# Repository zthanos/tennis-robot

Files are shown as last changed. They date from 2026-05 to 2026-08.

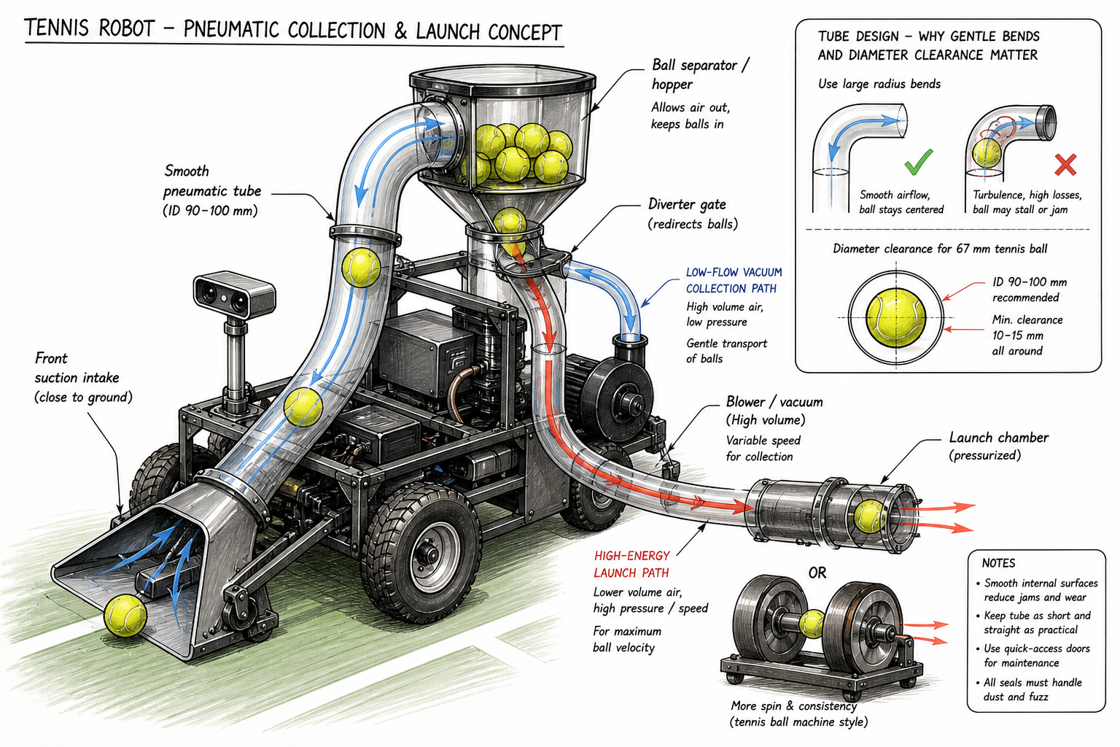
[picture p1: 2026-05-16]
docs/images/pneumatic-collection-launch-concept.png

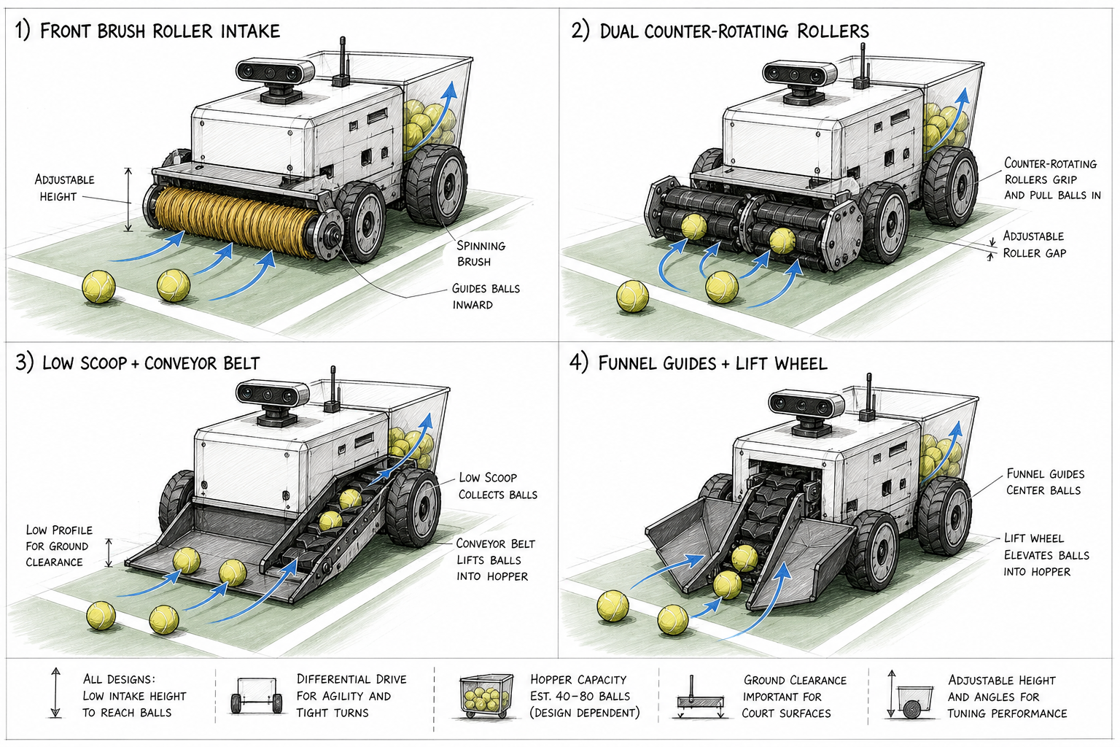
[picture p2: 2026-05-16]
docs/images/collector-concepts.png

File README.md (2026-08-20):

# Tennis Robot Simulation Starter

## Architecture Reset Notice

The current Webots controller and world are now treated as **legacy reference**
for the next implementation phase. New work should follow
`docs/process/architecture-implementation-guide-el.md` and the active baseline plans in
`docs/` before extending the existing controller behavior.

This is a first simulation-first experiment for a tennis-ball collecting and serving robot.

The initial goal is intentionally small:

- create a virtual tennis court;
- scatter tennis balls at random positions;
- place a differential-drive robot with a camera on the court;
- detect tennis balls from the camera stream using Python/OpenCV.

The project starts with **Webots + Python** because it is easier to get moving than a full ROS/Gazebo stack. ROS 2 can be added once perception and basic navigation behavior are proven.

## Project Layout

```text
controllers/
  ball_detector/
    ball_detector.py        # Webots Python controller
scripts/
  generate_balls.py         # Generate random Webots ball nodes
worlds/
  tennis_court.wbt          # Webots world
docker-compose.yml          # Optional Python dev container
Dockerfile                  # Optional Python/OpenCV environment
Dockerfile.webots           # Webots GUI container with noVNC
pyproject.toml              # Python deps managed with uv
```

## Quick Start

Install Webots on the host machine, then start local Webots and the remote-control console with:

```powershell
.\scripts\start_local_webots_control.ps1
```

Then press Play in Webots and open:

```text
http://127.0.0.1:8081
```

The script starts Webots with `USE_RGB_VISION=true` and points both Webots and the control panel at the same local `runtime/*.json` files. If Webots is installed somewhere unusual, pass the executable path:

```powershell
.\scripts\start_local_webots_control.ps1 -WebotsPath "C:\Path\to\webots.exe"
```

If Webots was already open, close it before running the script so it picks up the project Python/OpenCV environment. To force that from the script:

```powershell
.\scripts\start_local_webots_control.ps1 -RestartWebots
```

To run the ROS 2/Webots stack through WSLg with GPU acceleration, start it from
a WSL shell instead of Windows PowerShell:

```bash
cd /mnt/c/Users/thano/projects/diy/tennis-robot
bash scripts/start_local_webots_control_wslg.sh --build
```

The WSLg launcher uses the `ros2-wslg` Docker profile and defaults to the
`RX 7900 XTX` Mesa D3D12 adapter. Override it when needed:

```bash
bash scripts/start_local_webots_control_wslg.sh --adapter "AMD Radeon RX 7900 XTX"
```

The optional control panel runs from WSL and uses the project Python deps. If
WSL does not have `uv` yet:

```bash
curl -LsSf https://astral.sh/uv/install.sh | sh
source ~/.bashrc
```

You can still open the world manually:

```text
worlds/tennis_court.wbt
```

The robot controller is:

```text
controllers/ball_detector/ball_detector.py
```

When the simulation runs, the controller reads from the robot camera, detects tennis-ball-colored blobs, and draws detection rectangles on the Webots camera display.
The controller uses the simulated OAK depth stream for ball distance; RGB-only detections without valid depth are not converted into ball positions.
Detections are projected into robot-base and court/world XY coordinates using the front camera mount and the robot pose, so downstream navigation can reason in meters instead of image pixels.

The current world includes **Concept A: Funnel + Wide Intake Roller** as the front collector module:

- a level (un-pitched) 4WD skid-steer chassis with four driven 180 mm wheels, two per side (no casters);
- orange funnel plates and a low intake lip on the robot front;
- a rubber-like wide intake roller driven by `lift_wheel_motor` (historical device name);
- a transparent visual hopper raised for throw-mode gravity feed;
- a simulated intake zone that removes a tennis ball once the collector state machine captures it.
- a top-mounted `front_camera` plus aligned `front_depth` range finder representing the OAK-D-Lite AF RGB-D role for tennis-ball detection, depth, and targeted looks into shadow zones;
- a low-mounted 360-degree `front_lidar` representing the Waveshare/Slamtec RPLIDAR C1 role for real-time court boundaries, obstacles, range, shadow zones, and route costmaps.

## Robot Description Source

The robot description source is URDF xacro:

```text
ros2_ws/src/tennis_robot/urdf/tennis_robot.urdf.xacro
```

Component xacro files live under:

```text
ros2_ws/src/tennis_robot/urdf/components/
```

Edit the URDF xacro source when changing robot dimensions, wheel geometry,
sensor mounts, Gazebo sensor sections, or controller geometry constants.
Generate the runtime URDF locally with:

```powershell
uv run --with xacro python scripts/generate_robot_urdf.py
```

Inside the Gazebo Docker image, `ros-humble-xacro` is installed, so
`python3 scripts/generate_robot_urdf.py` is enough.

The Gazebo launch files regenerate this runtime file on every launch:

```text
runtime/tennis_robot.urdf
```

The tennis court world stays SDF and no longer includes `model://tennis_robot`.
Instead, the launch file spawns the generated URDF into Gazebo. To check whether
the generated URDF matches the xacro source:

```powershell
uv run --with xacro python scripts/generate_robot_urdf.py --check
```

The generated URDF is ignored by Git via `runtime/`. Treat it as a runtime/debug
view, not as a second source file.

The Webots court is modeled after the reference clay court photos:

- red clay playing surface with lighter wear/brush marks;
- off-white tennis lines;
- tall dark perimeter fencing for survey/depth measurements;
- side stone patio with planter boxes, a chair/umbrella area, floodlight poles, and green visual mass outside the court.

The controller behavior is:

```text
idle -> scan -> align -> approach -> capture -> collected
```

The Webots camera display overlays the current collector state and collected-ball count. The controller starts in `idle` and waits for a command from the Python control panel before it begins collecting. Ball distance is currently estimated from the top camera image, while the low 360-degree `front_lidar` provides range data for survey/navigation telemetry and the intended simulated contract for live obstacle mapping.

## Remote Control Console

Run the web remote-control console:

```powershell
uv run python scripts/control_panel.py
```

Then open:

```text
http://127.0.0.1:8081
```

Στο Raspberry Pi το κύριο ROS launch εκθέτει το operator console στο LAN. Για
αυτόνομο, WPA2/WPA3-protected Wi-Fi στο γήπεδο χωρίς router ή Internet, δες το
[Field Wi-Fi AP provisioning](docs/network/field-wifi-ap.md). Με τις default
ρυθμίσεις το τηλέφωνο ανοίγει `http://10.42.0.1:8081`.

The console has navigation for:

- **Dashboard**: requested mode, actual controller state, ball detection, collected count, and latest command stream.
- **Control**: send `idle`, `collect`, `collect_pattern`, `search`, and `survey` commands, plus a live court map with detected balls, same-side/across-net status, planned route, and pickup order.
- **Telemetry**: live robot pose, collector output, observation fields, survey target/range, and raw status JSON.
- **Command Stats**: per-mode command counts and last command metadata.
- **History**: recent command audit trail.

Use **Start Collection** to write `mode=collect` to `runtime/robot_command.json`; the Webots controller polls that file and starts the collector state machine. Use **Stop** to return the robot to `idle`. The controller also writes live diagnostics to `runtime/robot_status.json`, while command history is appended to `runtime/robot_command_history.jsonl`. You can override paths for both processes with `ROBOT_COMMAND_FILE`, `ROBOT_STATUS_FILE`, and `ROBOT_COMMAND_HISTORY_FILE` if the UI and Webots are launched from different working directories.
Use **Collect Pattern** to write `mode=collect_pattern`: the controller follows the half-court boundary/lane search pattern, interrupts on a same-side OAK-D target, hands off to the Concept A collector state machine, verifies collection, then resumes from the saved search marker.

To visualize the scan-first collection plan directly in Webots, start the controller with:

```powershell
$env:ROUTE_VISUALIZATION="true"
$env:ROUTE_VISUALIZATION_PRESET="fast"  # or "thorough"
```

When collection starts, the supervisor draws a route line on the court and ball markers for the current plan. `fast` hides risky balls from the plan; `thorough` shows the full reachable route for the robot's current side of the court. The overlay refreshes after simulated collection events and clears when the robot leaves collect mode.

Use **Survey court** to drive a boustrophedon measurement pattern across the court. The controller visits rows across the court, samples the front depth reading at each waypoint, and writes measurements to:

```text
runtime/court_survey.csv
```

The survey CSV includes robot position, heading, front range reading, distance to the four outer fences, and distances to the nearest singles sideline, doubles sideline, baseline, and service line.

The movement speed defaults are deliberately conservative in Docker:

```text
COLLECTOR_SCAN_ANGULAR_SPEED_RAD_S=0.35
COLLECTOR_MAX_ALIGN_ANGULAR_SPEED_RAD_S=0.45
COLLECTOR_ALIGN_ANGULAR_GAIN=1.4
COLLECTOR_APPROACH_SPEED_M_S=0.12
COLLECTOR_CAPTURE_SPEED_M_S=0.05
COLLECTOR_REVERSE_SPEED_M_S=0.08
ROBOT_MAX_WHEEL_SPEED_RAD_S=3.5
```

Increase `COLLECTOR_APPROACH_SPEED_M_S` only after the robot reliably keeps the ball in view during `align` and `approach`.

## Generate New Random Ball Positions

The world contains a marked block where tennis ball nodes are generated. To print a new deterministic set of balls:

With `uv` installed:

```powershell
uv run python scripts/generate_balls.py --count 18 --seed 7
```

Copy the output between the `# BALLS_START` and `# BALLS_END` markers in `worlds/tennis_court.wbt`.
By default the generator uses a realistic tennis-court bias: more balls near the net and the back court, fewer in open mid-court. Use `--distribution uniform` when you need an even random scatter for comparison.

## Optional Docker Dev Shell

Docker is useful for Python tooling and OpenCV experiments, but Webots GUI is usually simpler to run on the host or inside WSLg. The container uses `uv` too.

```powershell
docker compose run --rm sim-dev
uv run python scripts/generate_balls.py --count 18 --seed 7
uv run python -m py_compile controllers/ball_detector/ball_detector.py scripts/generate_balls.py
uv run python scripts/perception_smoke.py
uv run python scripts/collector_behavior_smoke.py
uv run python scripts/survey_behavior_smoke.py
```

## Webots In Docker

The `webots` compose service runs Webots in a virtual X display and exposes it through noVNC.

To start Webots with RGB vision and LiDAR enabled, and launch the remote-control console at the same time:

```powershell
.\scripts\start_webots_control.ps1
```

Then open:

```text
http://localhost:6080/vnc.html
http://127.0.0.1:8081
```

Use `-Build` the first time you want to rebuild the Docker image:

```powershell
.\scripts\start_webots_control.ps1 -Build
```

```powershell
docker compose up webots
```

Then open:

```text
http://localhost:6080/vnc.html
```

The service opens `worlds/tennis_court.wbt` automatically. This is convenient for a reproducible setup, but native Webots on Windows or WSLg may still be smoother for interactive editing.

## OpenSCAD In Docker

### GUI in the browser (no local install)

The `openscad-gui` service runs OpenSCAD on a virtual display and exposes it through noVNC (same idea as the Webots container). Port `6081` avoids clashing with Webots on `6080`.

```powershell
docker compose --profile cad up --build openscad-gui
```

Open:

```text
http://localhost:6081/vnc.html
```

It currently starts without a preloaded model because the old collector and
chassis SCAD files no longer match the active robot. Once a new active model is
added, open it from the mounted `cad/` directory or set `OPENSCAD_FILE`:

```powershell
$env:OPENSCAD_FILE="/workspace/cad/active_robot.scad"
docker compose --profile cad up openscad-gui
```

See `cad/README.md` for the current CAD status and mechanical sources of truth.
Files under `cad/` are the mounted repo workspace, so saves in the GUI write back to your project folder.

### Headless STL export

The `openscad` compose service uses the official `openscad/openscad:bookworm`
image to export future printable CAD files without a GUI:

```powershell
docker compose --profile cad run --rm openscad openscad -o cad/stl/active_robot.stl cad/active_robot.scad
```

## Telemetry

The Webots controller has optional OpenTelemetry instrumentation for simulation data:

- `robot.camera.frames`
- `robot.vision.ball.detections`
- `robot.vision.ball.area`
- `robot.vision.ball.distance`
- `robot.vision.ball.bearing`
- `robot.control.loop.duration`
- `simulation.step` traces

In Docker, telemetry is enabled for the `webots` service and sent to the local OpenTelemetry Collector:

```powershell
docker compose up webots otel-collector
docker compose logs -f otel-collector
```

To watch the robot controller state directly:

```powershell
docker compose logs -f webots
```

Useful controller log lines look like:

```text
control mode changed to collect
mode=collect collector=align visible=True distance=5.03m bearing=-29.5deg balls=0 ball_world=(-3.64,-2.49)
```

For local debugging without a collector, run with:

```powershell
$env:OTEL_ENABLED="true"
$env:OTEL_EXPORTER="console"
```

## Browser Route Simulator

Run the lightweight route simulation panel:

```powershell
uv run python scripts/simulation_panel.py
```

Then open:

```text
http://127.0.0.1:8082
```

This panel is a fast planning sandbox before deeper Webots work. It models the tennis court bounds, half-court or full-court movement area, random 40-50 ball dispersion, fixed obstacles, moving people with safety zones, travel speed, pickup time, scan time, periodic re-scans, and obstacle-aware route planning. During movement it performs continuous lookahead collision checks, pauses for emergency clearance, and replans if a dynamic obstacle enters the active path. It records telemetry for the run, including detected/collectable/blocked balls, total distance, total time, planned and runtime replans, safety stops, near misses, per-leg travel time, and scan/pickup/re-scan events.

## Route Benchmark

Run a Monte Carlo benchmark for the half-court scan/route strategy:

```powershell
uv run python scripts/route_benchmark.py --runs 100 --balls 40
```

The benchmark generates deterministic random scenarios with realistic ball bias, plans two-phase collection, estimates travel time from configured robot speed, and reports average collection rate, total time, distance, expected misses, blocked balls, net/wall risks, obstacle risks, scan events, and replans.

Enable the RPLIDAR C1-style costmap penalty when comparing the camera-only planner against OAK-D ball detection plus a live LiDAR obstacle map:

```powershell
uv run python scripts/route_benchmark.py --runs 100 --balls 40 --lidar-costmap --json-out runtime/route-benchmark-lidar-costmap.json --csv-out runtime/route-benchmark-lidar-costmap.csv
```

Write detailed outputs when comparing planner settings:

```powershell
uv run python scripts/route_benchmark.py --runs 100 --balls 40 --json-out runtime/route-benchmark.json --csv-out runtime/route-benchmark.csv
```

Generate learning-to-rank training data for a future next-ball policy model:

```powershell
uv run python scripts/route_benchmark.py --runs 1000 --balls 40 --training-out runtime/route-training.csv
```

Each training row represents one candidate ball at one planning decision. `selected=1` marks the ball chosen by the planner; `selected=0` marks alternatives. Features include robot pose, ball pose, estimated route distance, travel time, pickup-pose offset, risk type, miss probability, and distances to net, walls, and obstacles.

Train a baseline next-ball policy model from that CSV:

```powershell
uv run python scripts/train_next_ball_policy.py --training-csv runtime/route-training.csv --model-out runtime/next-ball-policy-model.json --metrics-out runtime/next-ball-policy-metrics.json
```

Evaluate the trained model against the planner on fresh scenarios:

```powershell
uv run python scripts/evaluate_next_ball_policy.py --runs 100 --balls 40 --seed 10000 --json-out runtime/next-ball-policy-eval.json --csv-out runtime/next-ball-policy-eval.csv
```

Generate outcome-labeled data when testing alternatives to planner imitation:

```powershell
uv run python scripts/generate_outcome_training.py --runs 300 --balls 40 --rollout-depth 0 --miss-penalty 12 --training-out runtime/route-outcome-training.csv
```

Evaluate a defer/edge-pass policy that leaves risky balls for a second pass:

```powershell
uv run python scripts/evaluate_defer_policy.py --runs 100 --balls 40 --seed 10000 --json-out runtime/defer-policy-eval.json --csv-out runtime/defer-policy-eval.csv
```

Add `--lidar-costmap` to evaluate the same defer/edge-pass policy using LiDAR-aware clearance costs.

The route strategy evaluator also has named presets:

- `thorough`: collect every reachable ball with the baseline LiDAR-aware route planner.
- `balanced`: defer obstacle-risk balls to a second pass, keeping collection coverage high at the cost of more time.
- `fast`: skip risky edge/obstacle balls for early physical tests where speed and low miss risk matter more than full collection.

```powershell
uv run python scripts/evaluate_defer_policy.py --runs 100 --balls 40 --lidar-costmap --strategy-preset fast --json-out runtime/strategy-fast-lidar-eval.json --csv-out runtime/strategy-fast-lidar-eval.csv
uv run python scripts/evaluate_defer_policy.py --runs 100 --balls 40 --lidar-costmap --strategy-preset balanced --json-out runtime/strategy-balanced-lidar-eval.json --csv-out runtime/strategy-balanced-lidar-eval.csv
uv run python scripts/evaluate_defer_policy.py --runs 100 --balls 40 --lidar-costmap --strategy-preset thorough --json-out runtime/strategy-thorough-lidar-eval.json --csv-out runtime/strategy-thorough-lidar-eval.csv
```

Evaluate the scan-first architecture: scan the court, build a batch plan, execute up to `--replan-every` pickups, and replan from the current position when a periodic or blocked-path trigger fires.

```powershell
uv run python scripts/evaluate_scan_replan_strategy.py --runs 100 --balls 40 --lidar-costmap --strategy-preset thorough --json-out runtime/scan-replan-thorough-lidar-eval.json --csv-out runtime/scan-replan-thorough-lidar-eval.csv
uv run python scripts/evaluate_scan_replan_strategy.py --runs 100 --balls 40 --lidar-costmap --strategy-preset fast --json-out runtime/scan-replan-fast-lidar-eval.json --csv-out runtime/scan-replan-fast-lidar-eval.csv
```

For a faster mode without using a preset, deliberately skip risky balls:

```powershell
uv run python scripts/evaluate_defer_policy.py --runs 100 --balls 40 --seed 10000 --skip-risky --json-out runtime/defer-policy-skip-risky-eval.json --csv-out runtime/defer-policy-skip-risky-eval.csv
```

## Next Milestones

Done:

1. Add depth estimation from camera geometry or a simulated depth camera.
2. Convert image detections into robot-base and court/world coordinates.
3. Add a simple behavior loop: rotate, detect nearest ball, drive toward it.
4. Test a simulated collector mechanism.

Next:

1. Add ROS 2 nodes and topics around camera frames, detections, and velocity commands.
2. Publish the world-coordinate detections to a route planner instead of only using the nearest visible ball.
3. Add jam/blocked-intake sensing to the collector state machine.

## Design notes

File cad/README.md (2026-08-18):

# Active CAD status

Active model: **`basket-bin-v2/`** — the sim-validated basket bin v2.1 +
entry hood (debug log #45-#56), parametric OpenSCAD with all dimensions in
`basket-bin-v2/params.scad`. Renders/exports run through the
`docker compose --profile cad` services.

Not yet modelled as manufacturing CAD: chassis frame, two-motor dual-wheel
intake and funnel — see below. Their current layout is documented in
`docs/hardware/chassis-layout-4wd-dual-intake-el.md`.

The previous `3d-printable-base` and `cyber-shell` models described superseded
single-roller, scoop, launcher, 760 x 430 mm chassis, and cosmetic-shell
concepts. They were removed from the working tree on the
`feat/dual-wheel-intake-concept` branch; Git history remains the archive.

`archive/single-motor-geared-intake/` is also historical: it visualizes the
rejected one-motor gear-train option. The active intake has two independent
motors, one per side-pinch wheel.

Current mechanical sources of truth:

- `ros2_ws/src/tennis_robot/urdf/tennis_robot.urdf.xacro`
- `ros2_ws/src/tennis_robot/urdf/components/basket.urdf.xacro`
- `docs/mechanism/dual-wheel-intake-design-el.md`
- `docs/mechanism/basket-bin-redesign-spec-el.md`
- `docs/mechanism/intake-debug-log-el.md`
- `docs/hardware/chassis-layout-4wd-dual-intake-el.md`

The next SCAD model should be generated from the validated 920 x 580 mm 4WD
chassis, dual-wheel intake, and basket v2.1 dimensions. Do not restore an old
model as the default without reconciling it against those sources.

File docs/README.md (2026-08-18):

# Tennis Robot Documentation

Active source-of-truth documents, grouped by topic. When a decision changes,
update the relevant baseline document first, then adjust CAD/software/tests.

## Structure

```text
docs/
  collection-route/   continuous collect_route: spec, design, plan, debug log, Nav2 controller
  perception/         OAK-D perception + measurement-covariance calibration
    covariance/       Gazebo covariance calibration reports (c2 / c2-v2 / c2-v3)
  survey/             court knowledge model + LiDAR court survey (v2) + SLAM
  mechanism/          active dual-wheel intake / funnel / basket + intake debug log
  hardware/           active 4WD layout, BOM, wiring, purchase lists, sensor contract
  process/            architecture guide, delivery contract, validation, board, telemetry
  images/             diagrams referenced by the build plans
  archive/  research/  superseded notes and broad exploratory research (background only)
```

## collection-route/
- `collection-route-rules-el.md` - active specification for the continuous collection route.
- `collection-route-design-el.md` - technical design.
- `collection-route-implementation-plan-el.md` - phased implementation plan.
- `collection-route-optimization-plan-el.md` - constraint register and measured plan for the shortest safe full route.
- `collection-route-phase7-acceptance-plan-el.md` - Gazebo acceptance scenarios (S1-S8).
- `collection-route-debug-log-el.md` - **running debug log** (every collect_route change lands here).
- `collection-nav2-controller-{rules,design,implementation-plan}-el.md` - C++ CollectionFollowPath controller.
- `collector-controller-cheat-sheet.md`, `collector-wiring-reference-el.md` - collector bring-up.
- `mission-dashboard-plan-el.md` - mission-control dashboard evolution plan.

## perception/
- `perception-oakd-sim-el.md` - simulated OAK-D pipeline / `BallDetectionArray` contract.
- `oak-d-adapter-contract.md` - OAK-D adapter contract.
- `perception-measurement-covariance-calibration-{rules,design,implementation-plan}-el.md`.
- `covariance/` - Gazebo perception-covariance calibration reports and scenario.

## survey/
- `court-knowledge-model-specification.md` - environment knowledge model + definition of done.
- `court-survey-v2-spec-el.md` - **active, as-built** LiDAR court survey spec.
- `slam-mapping-el.md` - SLAM mapping notes.

## mechanism/
- `intake-debug-log-el.md` - **running debug log** for the intake/collector mechanism.
- `dual-wheel-intake-design-el.md`, `intake-concept-decision-el.md`, `intake-bench-sweep-report-el.md`.
- `basket-bin-redesign-spec-el.md`.

## hardware/
- Purchase/build: `chassis-layout-4wd-dual-intake-el.md`, `prototype-purchase-list-el.md`, `hardware-bom-el.md`, `ordered-parts.md`.
- Wiring/setup: `motion-perfboard-wiring-el.md`, `ros2-control-migration-el.md`, `ubuntu-dual-boot-handoff.md`.
- Contracts: `sensor-topic-contract-el.md`, `hardware-glossary.md`.
- `../arduino/collector/` - Arduino bring-up sketches (collector motor, encoder, IR beam).

## process/
- `architecture-implementation-guide-el.md` - source-of-truth implementation guide.
- `feature-delivery-contract-el.md` - spec/design/plan workflow for substantial features.
- `pi-deployment-plan-el.md` - Raspberry Pi deployment + Humble→Jazzy migration plan.
- `validation-plan-el.md`, `project-board-plan-el.md`, `telemetry-architecture-el.md`.

## Archive

`docs/archive/` and `docs/research/` hold superseded plans and broad exploratory
research. Treat them as background only.

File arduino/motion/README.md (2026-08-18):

# Motion MCU (Arduino Mega) — drive firmware

`motion_mega/motion_mega.ino` — real-time / safety layer for the 4WD skid-steer
drive. Two BTS7960 drivers (one per side), four encoders. The host (PC now, Pi
later) sends high-level per-side duty over USB serial; the Mega handles arming,
ramp, timeout and E-stop. USB serial is host-agnostic, so what you validate on
the PC transfers unchanged to the Pi.

## Bench test (motors → PC)

1. **Power:** drive motors need a strong 12V supply (or the battery) — **NOT**
   the 12V/2A collector PSU (4 motors stall ~28A). USB only powers Arduino logic.
2. **Common ground:** Arduino GND + both BTS7960 GND + 12V PSU GND tied together.
3. **Wheels OFF the ground** for first runs.
4. Flash `motion_mega.ino` to the Mega.
5. Run the host test:
   ```bash
   uv run python scripts/test_motion_serial.py --port /dev/ttyACM0   # or COM5 on Windows
   ```
6. `arm` → `f 0.2` (forward, low duty) → watch encoder counts move. `stop`,
   then test `b`, `l`, `r`. Confirm each side's direction + encoder sign.
   Do **one side at a time** first: `m 0.2 0` then `m 0 0.2`.

## Serial protocol (115200, `\n`-terminated)

| Host → Mega | Meaning |
|---|---|
| `ARM` | enable drivers (only if E-stop ok) |
| `DISARM` | disable + stop |
| `M <left> <right>` | per-side duty, floats `[-1.0, 1.0]` (also a heartbeat) |
| `STOP` | target duty 0, stays armed (also a heartbeat) |
| `PING` | heartbeat only → replies `PONG` |

| Mega → Host | Meaning |
|---|---|
| `T <state> <Lduty> <Rduty> <encLF> <encLR> <encRF> <encRR> <estop>` | telemetry @10Hz |
| `OK ARM` / `OK DISARM <reason>` / `ERR <reason>` / `PONG` / `READY ...` | acks |

state: `0`=DISARMED `1`=ARMED `2`=ESTOP · estop: `1`=tripped `0`=ok

## Safety behaviour

- Boots **DISARMED** (drivers off, duty 0).
- `ARM` refused while E-stop tripped; a trip mid-run forces DISARM.
- **Command timeout** (`CMD_TIMEOUT_MS`, 300 ms): no heartbeat → duty goes to 0
  immediately (stays armed). The host script streams `M`/`PING` at 20 Hz.
- **PWM ramp** (`RAMP_PER_TICK`): ~0.5 s from 0→full, limiting current spikes
  that would otherwise trip the battery BMS in skid-steer turns.
- The physical START button arms from DISARMED after debounce. It does not move
  the motors by itself; movement still needs fresh `M left right` commands.
- The optional armed LED is driven by D34 through a suitable series resistor.

## Pin map

Matches `docs/hardware/motion-perfboard-wiring-el.md §4`:

| Function | Mega pin |
|---|---|
| LEFT_RPWM / LPWM / EN | D5 / D6 / D30 |
| RIGHT_RPWM / LPWM / EN | D9 / D10 / D31 |
| Encoders A (interrupt) | LF=D2, LR=D3, RF=D18, RR=D19 |
| Encoders B | LF=D22, LR=D23, RF=D24, RR=D25 |
| START_ARM / ESTOP_STATUS / ARMED_LED | D32 / D33 / D34 |
| IMU I2C (not used in v1) | SDA=D20, SCL=D21 |

## Notes / next steps

- v1 counts encoders on the A-edge only (direction from B). Fine for bench
  direction/odometry sanity; full 4× quadrature can come later if needed.
- The IMU (MPU6050) is wired to the Mega I2C but not read in v1.
- Later, a host node converts ROS `/cmd_vel` (Twist) → per-side duty and sends
  `M left right` — keeps the Mega dumb + safe. See `motion_controller.py`.

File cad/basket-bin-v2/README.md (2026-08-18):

# Basket bin v2.1 + entry hood — OpenSCAD

Manufacturing-reference model of the sim-validated basket (debug log
#45-#56): sunken removable wire-mesh bin, load-management tray, receiving
chute, front retention (corner guards + centre lip) and the chassis-mounted
entry hood that closed the 45-ball load gate.

All dimensions live in `params.scad` (mm, ground frame, +x forward) and are
copied from the validated sources — `docs/mechanism/basket-bin-redesign-spec-el.md`
and `ros2_ws/src/tennis_robot/urdf/components/basket.urdf.xacro`. Do not
edit a number here without re-validating in the Gazebo bench.

## Files

| File | Content |
| --- | --- |
| `params.scad` | Every dimension, with spec/log citations |
| `lib.scad` | Mesh-panel / wall / handle primitives (40 mm grid, 4 mm wire, 6 mm frame) |
| `bin.scad` | The removable weldment: floor, walls, tray, chute, guards, lip, flange, handles |
| `print-segments.scad` | Flat, tiled basket parts sized for a 220 x 220 mm print bed |
| `export-segment-stls.sh` | Batch export of all unique printable segment STLs |
| `hood.scad` | Chassis-mounted entry hood: inclined mesh roof + side cheeks + mounts |
| `chassis_context.scad` | Reference-only plate w/ real opening, battery, IR pair, scale balls |
| `assembly.scad` | Everything together; `-D 'explode=160'` lifts the bin out |

## Render / export

```bash
docker compose run --rm openscad openscad -o out.png cad/basket-bin-v2/assembly.scad
docker compose run --rm openscad openscad -o bin.stl --export-format binstl cad/basket-bin-v2/bin.scad
./cad/basket-bin-v2/export-segment-stls.sh
```

## Segmented 3D-print version (220 x 220 mm bed)

`print-segments.scad` turns the weldment into framed tiles instead of slicing
through mesh wires. Print the quantities below, then join adjacent 6 mm
perimeter frames with UV-resistant zip ties. For a stiffer connection, place a
`joiner_plate` across the seam and use zip ties through its holes, or clamp a
pair of plates with M4 bolts.

| STL | Quantity | Nominal footprint (mm) |
| --- | ---: | ---: |
| `floor_tile.stl` | 4 | 200 x 140 |
| `management_tray_tile.stl` | 2 | 140.4 x 140 |
| `side_wall_tile.stl` | 8 | 200 x 112.5 |
| `rear_wall_tile.stl` | 4 | 140 x 112.5 |
| `receiving_chute_tile.stl` | 1 | 50.2 x 180 |
| `side_flange_segment.stl` | 4 | 200 x 22 |
| `rear_flange_segment.stl` | 2 | 172 x 22 |
| `corner_guard.stl` | 2 | 50 x 20 |
| `center_lip.stl` | 1 | 180 x 10 |
| `carry_handle.stl` | 2 | 128 x 35 |
| `drop_strut.stl` | 4 | 10 x 6 |
| `joiner_plate.stl` | 24 recommended | 32 x 16 |

The tiling adds perimeter frames at every seam, so the printed version is
slightly heavier than `bin.scad` but keeps every mesh opening at or below the
validated 40 mm pitch. Use PETG or ASA for a court prototype; PLA is suitable
only for indoor fit checks. The hood remains a separate chassis-mounted part.

## Deliberate deviations from the sim model

1. **Hood cheeks trimmed to x 430-470** (sim: 420-470). The sim volume
   interpenetrates the bin's corner guards; fixed links never collide in
   Gazebo, but these are two separate physical parts. The leftover 10 mm
   slot above the guards is far below ball diameter — no functional change.
2. **Bin removal is hood-off-first.** The receiving chute (part of the bin
   weldment) sits between the hood cheeks; a straight vertical lift fouls
   the hood roof after ~85 mm. The hood mounts must therefore be bolted or
   hinged (flip-up), not welded. Removing/tilting the hood first gives a
   clean straight lift through the plate opening.
3. Mesh visuals in the sim are indicative wires; here the panels carry a
   real 6 mm perimeter frame and <= 40 mm grid pitch as buildable geometry.
4. The front floor skid (spec §2) is realised by the chute/floor frame rod
   radius; no separate part.

## Still open

- Hood mount detail: modelled as a transverse bar on the plate side strips
  (`hood_mounts()`); mounting off the funnel frame is the alternative if
  the bar shades the camera. Decide at frame build time.
- IR beam vs mesh alignment (locally larger grid eye if a wire lands on
  the beam line at x 445, z 70.5).
- Plywood-cut-list revision (spec §6.6) once the frame layout is frozen.

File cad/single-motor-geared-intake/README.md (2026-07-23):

# Single-motor geared intake concept

OpenSCAD-only concept view of the intake mechanism: one vertically mounted
GB37-style motor, a visible pitch-contact gear train, and two side-pinch
intake wheels. This is a mechanical visualization for discussion, not the
robot source of truth.

It intentionally does not modify or feed:

- `ros2_ws/src/tennis_robot/urdf/`
- Gazebo generated SDF files
- controller configuration
- runtime sweep artifacts

The current simulated intake direction remains documented in
`docs/mechanism/dual-wheel-intake-design-el.md`, where the validated default is two
motors. This CAD folder exists to inspect the packaging of the earlier
"one motor + gears" idea without touching robot behavior.

Render:

```bash
docker compose run --rm openscad openscad -o /tmp/single-motor-geared-intake.png cad/single-motor-geared-intake/assembly.scad
```

Useful preview toggles inside `assembly.scad`:

- `show_ball`
- `show_funnel_context`
- `show_drive_arrows`
- `show_pitch_circles`
- `explode_gears`

The idler centers are calculated from gear pitch radii so adjacent gears sit
on contact tangencies in top view. The left output path uses one idler; the
right output path uses two idlers so the two intake wheel shafts counter-rotate.

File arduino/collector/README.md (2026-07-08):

# Collector Arduino Bring-Up Sketches

Αυτός ο φάκελος έχει τα Arduino sketches για το πρώτο bench bring-up του
collector:

- TB6612FNG motor driver
- GB37Y3530 encoder motor
- 2x Adafruit IR break beam sensors

Άνοιξε κάθε `.ino` από το Arduino IDE μέσα από τον αντίστοιχο φάκελο.

## Pin Map

| Arduino Nano Pin | Χρήση |
|---|---|
| D2 | Encoder A |
| D3 | TB6612 PWMA |
| D4 | TB6612 AIN1 |
| D5 | TB6612 AIN2 |
| D6 | TB6612 STBY |
| D7 | Encoder B |
| D9 | IR Break Beam #1 receiver signal |
| D10 | IR Break Beam #2 receiver signal |
| 5V | TB6612 VCC, encoder VCC, IR sensors VCC |
| GND | Common ground |

## GB37Y3530 Motor Cable Colors

| Χρώμα καλωδίου | Αντιστοιχεί σε | Σύνδεση σε αυτό το prototype |
|---|---|---|
| Κόκκινο | Motor lead | TB6612 `AO1` |
| Μαύρο | Motor lead | TB6612 `AO2` |
| Μπλε | Encoder A | Arduino Nano `D2` |
| Πράσινο | Encoder B | Arduino Nano `D7` |
| Κίτρινο | Encoder VCC | `5V` |
| Λευκό | Encoder GND | `GND` |

Αν ο roller γυρίζει ανάποδα, άλλαξε τη φορά στο software ή αντάλλαξε τα δύο
motor leads `AO1`/`AO2`. Μην αλλάξεις τα καλώδια του encoder για να διορθώσεις
τη φορά του μοτέρ.

## Προτεινόμενη Σειρά Δοκιμών

1. `01_ir_beam_test`
   - Επιβεβαιώνει ότι τα 2 IR receivers διαβάζονται σωστά.
   - Δεν χρειάζεται 12V στο `VM`.

2. `02_encoder_hand_test`
   - Επιβεβαιώνει ότι ο encoder δίνει pulses όταν γυρίζεις τον άξονα με το χέρι.
   - Δεν χρειάζεται να κινείται το μοτέρ από τον driver.

3. `03_motor_tb6612_test`
   - Επιβεβαιώνει ότι ο TB6612 γυρίζει το μοτέρ εμπρός/πίσω.
   - Χρειάζεται `+12V -> VM` και κοινό `GND`.
   - Ξεκινά με χαμηλό PWM για να προστατεύσει τον driver.

4. `04_collector_smoke_test`
   - Τρέχει motor + encoder + 2 IR beams μαζί.
   - Είναι το πρώτο ολοκληρωμένο smoke test του collector.

5. `05_wiring_diagnostic`
   - Δείχνει στο Serial Monitor αν φαίνονται σωστά IR, encoder και TB6612 pin map.
   - Έχει εντολή `p` για σύντομο pulse 300 ms στο τρέχον PWM, ώστε να ελέγξεις `VM`, κοινό `GND`, `AO1`/`AO2`, `PWMA`, `AIN1`, `AIN2` και `STBY`.
   - Η hardware δοκιμή που πέρασε στις 28/06/2026 χρησιμοποίησε Serial `9600 baud`, `START_PWM=255` και `MAX_SAFE_PWM=255`.
   - Ξεκίνα με `i`, μετά σπάσε κάθε IR beam, γύρισε τον άξονα με το χέρι, και τέλος δοκίμασε `p`.

6. `06_motor_driver_wiring_check`
   - Ελέγχει μόνο Arduino Nano -> TB6612FNG -> motor, χωρίς IR και encoder.
   - Ξεκίνα με την εντολή `v` και μέτρα `VCC=5V`, `VM=12V`, κοινό `GND`.
   - Μετά δοκίμασε `p` για ένα πολύ σύντομο χαμηλό-PWM pulse.

## Πριν Βάλεις 12V Στο VM

Μέτρα με πολύμετρο πάνω στα pins του TB6612:

| Μέτρηση | Αναμενόμενο |
|---|---|
| `VCC` προς `GND` | περίπου 5V |
| `VM` προς `GND` | περίπου 12V |
| `Arduino GND` προς `TB6612 GND` | συνέχεια / σχεδόν 0 ohm |
| `AO1` και `AO2` | μόνο προς τα δύο καλώδια του μοτέρ |

Αν δεις 12V στο `VCC`, σταμάτα. Το `VCC` είναι μόνο για 5V λογικής.

## Serial Monitor

Για τα sketches `01` έως `05`:

```text
Baud rate: 115200
Line ending: No line ending
```

Για το hardware-validated `06_motor_driver_wiring_check`:

```text
Baud rate: 9600
Line ending: No line ending
```

## IR Logic

Τα Adafruit IR break beam receivers είναι open-collector και τα sketches
χρησιμοποιούν:

```cpp
pinMode(pin, INPUT_PULLUP);
```

Με αυτό το wiring:

```text
LOW  = beam broken / blocked
HIGH = beam unbroken / receiver sees emitter
```

Το runtime sketch `collector_driver` διαβάζει και τα δύο IR beams με debounce
`25 ms` και στέλνει status σε αλλαγή ή heartbeat κάθε `500 ms`:

```text
ir:<entry_broken>,<exit_broken>,<cycle_state>
```

Παράδειγμα `ir:1,0,moving_to_exit`: το entry beam είναι κομμένο, το exit beam
είναι ελεύθερο και η μπάλα κινείται προς το exit.

Η αυτόματη ακολουθία του runtime sketch είναι:

1. `entry=BROKEN`: εκκίνηση του roller προς τα εμπρός.
2. `exit=BROKEN`: η μπάλα έφτασε στο exit.
3. `exit=CLEAR`: η μπάλα πέρασε, ο roller σταματά.
4. Νέος κύκλος οπλίζει μόνο αφού το `entry` γίνει ξανά `CLEAR`.

Αν το `exit` δεν ολοκληρώσει τη μετάβαση μέσα σε `5 s`, το sketch σταματά τον
roller, αναφέρει `timed_out` και οπλίζει ξανά μόνο όταν καθαρίσουν και τα δύο
IR beams.

## Motor Driver Προσοχή

Ο TB6612FNG είναι μικρός driver για το GB37Y3530, ειδικά αν ο roller κολλήσει.
Τα motor tests χρησιμοποιούν χαμηλό PWM. Αν ο driver ζεσταθεί, κάνει reset, ή το
μοτέρ τραβήξει απότομα, σταμάτα το test.

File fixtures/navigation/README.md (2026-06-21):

# Navigation replay fixtures

These fixtures capture real robot telemetry so navigation changes can be
regression-tested against behavior that was observed in Gazebo.

## Survey fixtures

Run every survey replay fixture:

```powershell
.\.venv-win\Scripts\python.exe scripts\replay_navigation_fixtures.py
```

Run one fixture directly:

```powershell
.\.venv-win\Scripts\python.exe scripts\replay_ros2_lidar_survey.py fixtures\navigation\survey\find_baseline_fence_stuck_2026-06-05.jsonl
```

Check whether a recording contains a complete command trace:

```powershell
.\.venv-win\Scripts\python.exe scripts\replay_survey_cmd_vel.py runtime\survey_replay_latest.jsonl
```

Inside the ROS/Gazebo container, a command trace can be replayed to `/cmd_vel`
with:

```bash
python3 /workspace/scripts/replay_survey_cmd_vel.py /workspace/runtime/survey_replay_latest.jsonl --publish
```

Only recordings made after `cmd_linear_m_s` and `cmd_angular_rad_s` were added
to `survey_replay_record.py` can be replayed this way.

`find_baseline_fence_stuck_2026-06-05.jsonl` documents the run where the survey
confirmed the net, entered the 180-degree baseline leg, then drove into the
fence. The regression check now asserts that a required turn emits no forward
command until the turn is complete, and that queued decision processing does
not emit a fence-reached event in the same tick as an earlier survey event.

`baseline_full_turn_still_find_baseline_2026-06-05.jsonl` captures the next
case: the baseline 180-degree turn completes before the first forward command,
but the replay still remains in `find_baseline`. Use it for the next phase of
the survey state-machine fix.

`long_side_inside_court_timeout_2026-06-05.jsonl` is the first fixture with a
complete command trace. Live telemetry shows the robot turns to the long-side
leg before `left_sideline_to_fence_m` is recorded, then drives the long side at
y around -4.6 to -5.0 instead of staying clearly outside the sideline path.

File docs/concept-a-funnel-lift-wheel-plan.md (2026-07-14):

# Concept A: Funnel + Wide Intake Roller Plan

> **Historical / superseded:** Concept A and its OpenSCAD models were replaced
> by the dual-wheel intake and basket v2.1. This file remains as project history,
> not as an active manufacturing plan. See `cad/README.md` for current sources.

Last checked: 2026-05-16

This document turns Concept A into a two-phase build plan:

1. **Collect MVP**: find, approach, capture, and store tennis balls.
2. **Throw Phase 2**: add controlled feeding and a dual-flywheel launcher.

Costs are rough prototype estimates and exclude shipping, VAT/import duties, local reseller markups, spare parts, machining, 3D printing, and failed experiments.

## Goal

Build the simplest useful version of the tennis robot architecture:

```text
OAK-D RGB-D ball detection + low 360-degree LiDAR obstacle map -> base alignment -> front funnel -> wide intake roller -> small hopper
```

Then extend the same architecture:

```text
collect-mode hopper -> raised/tilted throw-mode hopper -> gravity feed gate -> dual flywheels -> short guarded launch barrel
```

The important decision is to keep collection and throwing modular. The first machine should prove that the base can locate and collect balls reliably before we add high-energy launch hardware.

## Phase 1: Collect MVP

### Recommended Assembly Sketch

Concept A recommended assembly sketch

### Collector-To-Base Assembly

Collector to base assembly diagram

### Base Layout Plan

Base layout plan

Historical CAD source: commit `de75682`, path
`cad/3d-printable-base/base_mounting_plate.scad`.

Plywood cutting instructions:

```text
docs/plywood-cut-list.md
```

Physical-store purchase checklist:

```text
docs/prototype-purchase-list-el.md
```

The same CAD model also includes the vertical mounting frame by default
(`show_verticals=true`): upper rails, electronics trays, collector uprights,
battery retainers, handle rails, and reserved launcher/feed uprights.

Sensor mounting intent:

```text
Waveshare/Slamtec RPLIDAR C1, low on the body, with 360-degree line of sight around the robot
  -> real-time obstacle/court-edge costmap + shadow zones
top OAK-D S2, rigidly mounted above the intake/upper frame
  -> primary ball detection, depth, and targeted looks into LiDAR shadow zones
```

Keep the LiDAR mount clear of the front funnel lips and the four drive wheels.
The scan plane should be low enough to see real obstacles and court boundaries,
but tennis balls should remain an OAK-D target. The OAK-D mount should be higher
and stiffer, with a repeatable downward/front angle for calibration.

Assembly intent:

```text
base front plate
  -> left/right funnel side plates
  -> fixed or adjustable back plate
  -> wide intake roller + motor bracket
  -> small transparent hopper/bin
  -> required IR break-beam ball-present sensor at throat or hopper entry
  -> recommended second IR break-beam near the roller for jam/partial-capture detection
```

Keep these four adjustments reachable without removing the collector from the robot:

- bottom lip height
- funnel side angle
- roller gap/compression
- roller angle/speed

The preferred first build is not a sealed beautiful mechanism. It is a tunable rig that can tell us what geometry actually works on a court-like surface.

### Updated Chassis Geometry

This superseded CAD direction used a level (un-pitched) 4WD chassis:

- four identical driven 180 mm wheels, two per side, placed symmetrically about the chassis center (no casters), so the body stays flat;
- the two motors on each side are wired in parallel to one BTS7960 driver (4WD skid-steer), giving more traction and eliminating the caster scrub that previously stalled in-place turns;
- the bin has two modeled positions: a lower collect-mode reference and a raised/tilted throw-mode position;
- throw mode uses a gravity feed chute from the raised bin into the flywheel throat.

These dimensions are historical and must not be used for cutting or drilling.
The removed models remain available at commit `de75682`; current mechanical
sources are listed in `cad/README.md`.

### Scope

The Collect MVP should do one job well:

1. detect one visible tennis ball
2. estimate `bearing_rad` and `distance_m`
3. rotate/drive the base toward the ball
4. slow down near the ball
5. guide the ball into a front funnel
6. pinch/pull the ball with the wide roller into a small hopper/bin
7. confirm collection with an IR break-beam at the throat or hopper entry

### Use The Base Capabilities

The current simulation already gives us the right control signals for a first collector:

| Base capability | Current source | How it helps collection |
|---|---|---|
| Low 360-degree LiDAR sweep | simulated `front_lidar`, physical lower LiDAR | Builds the live obstacle/court-edge costmap and shadow zones so the robot avoids a slow survey pass. |
| RGB tennis ball detection | `controllers/ball_detector/perception.py`, physical top OAK-D | Finds tennis balls by color/shape and later neural detection. |
| Bearing estimate | OAK-D ball observation | Lets the base center the ball before pickup. |
| Distance estimate | OAK-D depth/monocular fallback | Lets the base switch from approach to slow capture. |
| Differential drive control | left/right wheel motor velocity | Allows `scan -> align -> approach -> capture` behavior without a steering mechanism. |
| Telemetry | `robot.vision.ball.*`, `robot.control.loop.duration` | Helps tune detection stability, approach speed, and capture behavior. |

For the physical robot, the base should expose the same logical contract:

```text
ball_observation:
  visible: bool
  bearing_rad: float
  distance_m: float
  confidence: float

base_command:
  linear_speed_m_s: float
  angular_speed_rad_s: float

collector_command:
  lift_wheel_speed: float
  intake_enabled: bool
```

`lift_wheel_speed` remains the software/control field for compatibility with the current Webots device name. Mechanically, the preferred collector is now a full-width compliant intake roller, not a narrow centered wheel.

### Mechanical Concept

The front module is intentionally simple:

```text
wide low funnel -> full-width compliant roller -> adjustable back plate/ramp -> ball shelf/hopper
```

Suggested starting dimensions:

| Feature | Starting target | Why |
|---|---:|---|
| Funnel mouth width | 260-340 mm | Forgives approach error and bearing noise. |
| Effective roller capture width | 220-280 mm | Uses a wider contact patch so the robot does not need perfect centering. |
| Roller fore-aft placement | As close to the front edge as practical; roller contact line should be the first hard contact after the low scoop | Prevents the chassis or funnel floor from pushing the ball away before capture. |
| Transfer throat width after roller | 75-95 mm | Keeps the hopper/feed path controlled after pickup. |
| Bottom lip height | 5-12 mm | Low enough to catch the ball, high enough to avoid scraping. |
| Roller diameter | 60-90 mm | Easy to source or print; enough contact patch without lifting the front too high. |
| Roller gap to back plate/ramp | 55-65 mm adjustable | Needs tuning for tennis ball fuzz and compression. |
| Hopper capacity | 3-6 balls | Enough for MVP without complicating sorting. |

The first prototype should have adjustable slots for funnel height, roller gap, roller angle, and roller fore-aft position. The roller shaft should be supported at both ends because the wider cylinder will flex more than a narrow wheel.

### Phase 1 Bill Of Materials

| Priority | Component | Qty | Est. unit cost | Est. subtotal | Notes |
|---|---:|---:|---:|---:|---|
| Required | Funnel side plates, PETG/ABS print or 2-3 mm plastic sheet | 1 set | US $10-$40 | US $10-$40 | Can be 3D printed or cut from sheet plastic. |
| Required | Wide compliant intake roller/cylinder, 240-300 mm length, 60-90 mm diameter | 1 | US $15-$45 | US $15-$45 | Prefer soft rubber/PU/TPU over hard plastic. |
| Required | DC gear motor for intake roller | 1 | US $15-$50 | US $15-$50 | Start around 100-300 RPM, enough torque to pinch a ball. |
| Required | Motor driver for collector motor | 1 | US $10-$30 | US $10-$30 | Small H-bridge is enough unless using a large motor. |
| Required | Bearings, long shaft, hubs/couplers | 1 set | US $20-$55 | US $20-$55 | Support both roller ends and make the roller easy to remove. |
| Required | Brackets, fasteners, inserts, standoffs | 1 set | US $20-$60 | US $20-$60 | Expect iteration here. |
| Required | Small hopper/bin panels | 1 | US $10-$35 | US $10-$35 | Transparent plastic is useful for debugging. |
| Required | IR break-beam ball-present sensor at hopper throat | 1 | US $3-$15 | US $3-$15 | Primary `collection_confirmed` signal for the physical MVP. |
| Required | Waveshare/Slamtec RPLIDAR C1 360-degree 2D LiDAR and lower-body protective bracket | 1 | EUR 80-100 | EUR 80-100 | Live obstacle/court-edge costmap and shadow-zone sensor. Do not rely on it for tennis-ball detection. |
| Required | Top OAK-D S2 camera mount, USB3 cable, and vibration isolation | 1 set | US $25-$60 | US $25-$60 | Keeps RGB-D ball detection calibrated above the intake/upper frame. |
| Recommended | Second IR break-beam near roller/throat entry | 1 | US $3-$15 | US $3-$15 | Helps detect partial captures and jams before the ball reaches the hopper. |
| Recommended | Emergency stop switch | 1 | US $10-$30 | US $10-$30 | Required before real moving tests. |
| Optional | 100 mm smooth tube/duct section for later feed path tests | 1 | US $8-$25 | US $8-$25 | Good clearance for tennis balls; avoid tight bends. |

Estimated Phase 1 collector module total:

- **Lean bench prototype**: US $80-$150
- **Mobile-ready collector MVP**: US $150-$280
- **With base electronics already available**: no extra perception cost
- **With low RPLIDAR C1 + top OAK-D S2 sensors added**: add about US $450-$520 minimum from the hardware list

### Phase 1 Acceptance Criteria

The Collect MVP is successful when it can:

| Test | Target |
|---|---|
| Center approach | Ball enters the funnel from 1.5-2.0 m away with less than 2 approach corrections. |
| Offset approach | Ball still collects when initial alignment is off by about 130-160 mm. |
| Slow capture | Base slows before contact and does not push the ball away. |
| Lift reliability | 8 of 10 balls move from floor to hopper on flat court-like surface. |
| Jam recovery | A stuck ball can be cleared without disassembling the whole front module. |
| Telemetry/debug | Logs or console output show detection, bearing, distance, and collector state. |

### Phase 1 Software Tasks

| Task | Output |
|---|---|
| Add behavior states | `scan`, `align`, `approach`, `capture`, `reverse_clear`, `collected`. |
| Add near-ball stop distance | Use `distance_m` threshold before entering capture speed. |
| Add collector command abstraction | Keep intake roller control separate from drive control. |
| Add simulated collection event | In Webots, mark a ball as collected when it reaches the intake zone. |
| Add IR break-beam collection confirmation | Physical MVP should feed a throat/hopper IR break-beam into `collection_confirmed`; simulation should keep an equivalent signal. |
| Add telemetry fields | Collector state, collection attempts, successful captures, jam timeout. |

## Phase 2: Throw

### Scope

Phase 2 adds a launcher only after collection is repeatable. The launcher should be a rear/top module so it does not disturb the front intake.

```text
raised/tilted hopper -> gravity feed chute -> metering/feed gate -> dual counter-rotating flywheels -> short guarded barrel
```

This should start as a bench module before it is mounted on the mobile base.

### Phase 2 Bill Of Materials

| Priority | Component | Qty | Est. unit cost | Est. subtotal | Notes |
|---|---:|---:|---:|---:|---|
| Required | Throwing wheels or high-friction flywheels | 2 | US $40-$130 | US $80-$260 | Tennis machine replacement wheels are convenient but not cheap. |
| Required | High-speed DC/BLDC launch motors | 2 | US $30-$100 | US $60-$200 | Final choice depends on target ball speed. |
| Required | Motor drivers / ESCs for launch motors | 2 | US $20-$80 | US $40-$160 | Must match motor type and current draw. |
| Required | Feed gate servo or small geared motor | 1 | US $10-$40 | US $10-$40 | Releases one ball at a time. |
| Required | Short launch barrel / guarded guide | 1 | US $20-$80 | US $20-$80 | Guide, not a pressure tube. Keep fingers away from wheels. |
| Required | Launcher frame, guards, fasteners | 1 set | US $50-$150 | US $50-$150 | Guarding is part of the design, not an add-on. |
| Required | Battery/regulator upgrade | 1 set | US $60-$200 | US $60-$200 | Launch motors will dominate power budget. |
| Required | Safety interlock / arming switch | 1 | US $10-$40 | US $10-$40 | Needed before spin-up tests. |
| Recommended | RPM sensors | 2 | US $5-$25 | US $10-$50 | Needed for repeatable throws. |
| Optional | Pan/tilt aim adjustment | 1 set | US $40-$150 | US $40-$150 | Defer unless fixed-angle launch is too limiting. |

Estimated Phase 2 launcher module total:

- **Bench launcher only**: US $330-$650
- **Mobile-mounted launcher with power and safety**: US $450-$900

### Phase 2 Acceptance Criteria

| Test | Target |
|---|---|
| Single-ball feed | One ball enters flywheels per feed command. |
| Spin-up stability | Wheel speed reaches target before feed gate opens. |
| Repeatable launch | Ball exits within a consistent direction/speed band. |
| Safe idle | Feed gate cannot open unless launcher is armed and wheels are ready. |
| Mechanical access | Wheels and feed path can be inspected and cleared safely. |

## Suggested Build Order

1. Simulate the collection state machine using current camera detection.
2. Print or cut the front funnel with adjustable throat and lip.
3. Bench-test roller gap, speed, shaft support, and ball compression by hand-feeding balls.
4. Mount the collector to the base and test slow approach.
5. Add IR break-beam ball-present sensing for collection confirmation.
6. Tune approach speed and capture speed using telemetry.
7. Freeze the collector interface: hopper exit height, ball spacing, and feed direction.
8. Build Phase 2 launcher as a separate bench module.
9. Add feed gate and safety interlocks.
10. Mount launcher only after bench throws are predictable.

## Current Cost Summary

| Build level | Estimated cost |
|---|---:|
| Collector bench MVP only | US $80-$150 |
| Collector mobile MVP, excluding base and camera | US $150-$280 |
| Collector MVP with low LiDAR + top OAK-D sensor path | US $600-$780 |
| Launcher bench module | US $330-$650 |
| Full Concept A prototype, excluding mobile base | US $480-$1,180 |
| Full Concept A with mobile base still to be selected | Add roughly US $250-$800 |

## Buying Strategy

Buy now for Collect MVP:

- funnel material / filament
- one wide compliant intake roller/cylinder
- one DC gear motor
- one motor driver
- shaft/bearings/fasteners
- emergency stop switch
- IR break-beam ball-present sensor

Do not buy yet:

- launch motors
- launcher ESCs/drivers
- expensive throwing wheels
- large battery pack
- pan/tilt launcher hardware

The launcher depends on the hopper height, ball feed direction, and available power budget, so buying those parts too early risks locking us into the wrong geometry.

## Reference Price Anchors

These links are not final purchase recommendations; they anchor the rough cost ranges:

- OAK-D S2 camera and hardware docs: https://new-store.luxonis.com/products/oak-d-s2 and https://docs.luxonis.com/hardware/products/OAK-D%20S2
- Slamtec RPLIDAR C1 reference: https://www.slamtec.com/en/C1/
- Example 100 mm flexible duct pricing: https://www.airconcentre.co.uk/products/devola-100mm-pvc-flexible-ducting-3m-dvfd1003
- Example tennis-machine throwing wheel: https://www.tenniswarehouse.com.au/spinfire-throwing-wheel.html
- Example pair of Tennis Tutor Cube replacement wheels: https://www.clarkesports.net/product-page/tennis-tutor-cube-throwing-wheel-replacements-2
- BTS7960 motor-driver voltage/current class reference: https://www.handsontec.com/dataspecs/module/BTS7960%20Motor%20Driver.pdf

## Open Decisions

| Decision | Default for now |
|---|---|
| Sensor stack | Top OAK-D S2 for ball detection; low 360-degree LiDAR for live obstacle/court mapping and shadow zones. |
| Collector motor voltage | 12 V DC for simple sourcing. |
| Hopper capacity | Start with 3-6 balls. |
| Launch architecture | Dual flywheel, fixed angle at first. |
| Mobile base | 4WD skid-steer base: four driven 180 mm wheels (two per side, parallel-wired per BTS7960), level body geometry, no casters. |

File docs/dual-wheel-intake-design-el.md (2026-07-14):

# Dual-wheel intake — design spec

Ημερομηνία: 2026-07-10
Branch: `feat/dual-wheel-intake-concept`

Αυτό το έγγραφο ορίζει τη γεωμετρία, τη φυσική και τα κριτήρια αποδοχής του
dual-wheel intake που αντικαθιστά το single top-roller concept. Η απόφαση
εγκατάλειψης του top roller τεκμηριώνεται στο
`docs/intake-concept-decision-el.md` και στο
`docs/intake-bench-sweep-report-el.md`.

## Αποφάσεις χρήστη (2026-07-10)

```text
1. Διάταξη: οριζόντιο (πλευρικό) pinch — δύο τροχοί σε ΚΑΤΑΚΟΡΥΦΟΥΣ άξονες,
   ένας αριστερά και ένας δεξιά ενός κεντρικού διαδρόμου.
2. Καταμερισμός ρόλων:
   - funnel  -> centering (οδηγεί τη μπάλα στο κέντρο του διαδρόμου)
   - wheels  -> capture + transport (πιάνουν τη μπάλα και τη στέλνουν πίσω)
   - ramp    -> elevation + guidance προς το basket
3. Κίνηση: ΔΥΟ πανομοιότυπα μοτέρ (ίδιο μοντέλο με του παλιού top roller),
   ένα ανά τροχό, αντίθετης φοράς. Αντικαθιστά την αρχική ιδέα
   "ένα μοτέρ + γρανάζια". Συνέπεια BOM: +1 μοτέρ.
```

## Τι αφαιρείται / τι μένει

Αφαιρούνται (γεωμετρία που υπήρχε ΜΟΝΟ για τον top roller):

- `intake_roller` macro / `lift_wheel_link` ως οριζόντιος roller
  (drivetrain.urdf.xacro)
- το bite lip ως backstop του roller (το impulse δίνεται πλέον από το pinch,
  όχι από αντίσταση lip-roller)
- κάθε spiral/paddle/carriage κατασκευή του παλιού debugging trail

Μένουν:

- funnel cheeks (centering) — `funnel.urdf.xacro`
- ramp/scoop mesh (elevation) — `generate_curved_scoop_mesh.py`, με
  προσαρμογές entry (βλ. παρακάτω)
- basket, IR beams, intake debug camera
- το deterministic bench + release-criteria tooling

## Γεωμετρία (nominal — όλα sweep-able)

Σταθερές αναφοράς: μπάλα ⌀66 mm (r=33), rest z=33 mm (μετά το court fix),
funnel mouth συγκλίνει σε 180 mm στο intake, cheeks στα y=±145 mm,
funnel_link frame: ground = funnel_z − 0.038 m.

```text
intake_wheel_left_link / intake_wheel_right_link
  Σχήμα           κύλινδρος, κατακόρυφος άξονας (revolute joint στο z)
  Ακτίνα Rw       0.060 m            (sweep 0.050-0.070· βλ. motor ισοζύγιο)
  Ύψος            0.080 m, z 0.005-0.085 ground
                   (καλύπτει τον ισημερινό της μπάλας z=33)
  Nip x           0.590 m ground     (sweep ±0.02 — κοντά στο σημερινό lip)
  Κέντρα y        ±(gap/2 + Rw) = ±0.090 m για gap 60 mm
  Gap g           0.060 m            (3 mm interference/πλευρά, sweep 0.056-0.066)
  Υλικό επαφής    μ=2.5 (λάστιχο/αφρός, όπως τα paddles)
```

### Λατερική ενδοτικότητα (υποχρεωτική — δίδαγμα test1/test2)

Μπάλα και τροχοί είναι rigid bodies στο DART: interference = σφήνωμα,
clearance = μηδενική πρόσφυση (αποδεδειγμένο στα collect_test1/2). Άρα το
"3mm interference/πλευρά" ΔΕΝ μπορεί να είναι rigid — κάθε τροχός κρεμιέται
σε **prismatic y-carriage με ελατήριο** (το αποδεδειγμένο SDF
`<spring_stiffness>` patch του log #9):

```text
Carriage joint   prismatic, axis 0 1 0 (left) / 0 -1 0 (right)
Travel           0..+8 mm προς τα έξω (κάτω stop στο rest gap)
Spring k         ~1000 N/m αρχικά (sweep axis μαζί με το rest gap)
Rest gap         0.060 m (3 mm interference/πλευρά που γίνεται grip force)
```

Γιατί εδώ δουλεύει ενώ στο top roller απέτυχε (log #13): εκεί η απαιτούμενη
διεύθυνση υποχώρησης ΠΕΡΙΣΤΡΕΦΟΤΑΝ κατά μήκος της τροχιάς (ακτινική γύρω
από τον roller) και το 1-DOF κατακόρυφο ελατήριο δεν την κάλυπτε· εδώ η
διαδρομή είναι ευθεία και η απαιτούμενη υποχώρηση είναι ΣΤΑΘΕΡΑ ±y σε όλο
το πέρασμα — ακριβώς ο βαθμός ελευθερίας του carriage.

Έλεγχοι χωροθέτησης που πρέπει να περάσουν στη Φάση 1 (offline, στο
γεννημένο SDF):

```text
- wheel bottom (z=0.005) > ramp top στο nip x            (ramp εκεί ~0.001-0.004)
- wheel outer edge (y=±0.150) δεν τέμνει τα funnel cheeks (y=±0.145 —
  ΟΡΙΑΚΟ: πιθανώς τα cheeks κοντύνουν ή μετατοπίζονται μπροστά από το nip)
- wheel κύλινδροι δεν τέμνουν chassis/ramp/deflector
- nip centerline ευθυγραμμισμένο με ramp centerline (y=0)
```

## Λειτουργική φιλοσοφία

```text
capture -> transport -> guide -> hopper
```

Η μπάλα δεν εκτοξεύεται (το launch model ήταν του παλιού concept)· οι τροχοί
τη συλλαμβάνουν και τη μεταφέρουν ενεργά μέσα από το throat, και η ράμπα την
καθοδηγεί στο hopper. Κάθε στάδιο επικυρώνεται χωριστά (βλ. Concept
Validation Plan στο decision doc).

## Φυσική: γιατί το pinch δουλεύει εκεί που ο top roller απέτυχε

Ο top roller απέτυχε γιατί ζητούσε ταυτόχρονα αντίσταση για bite και
απελευθέρωση για launch από ΜΙΑ ενεργή επιφάνεια (βλ. decision doc). Στο
πλευρικό pinch:

- Δύο ενεργές επιφάνειες οδηγούν ΚΑΙ οι δύο προς τα πίσω (−x): η μπάλα
  παίρνει καθαρή rearward ταχύτητα ~ίση με το surface speed, χωρίς να
  χρειάζεται τρίτη επιφάνεια αντίστασης.
- Η ενδοτικότητα που έλειπε (radial compliance, log #13) εδώ είναι εγγενής:
  η συμπίεση είναι συμμετρική στο οριζόντιο επίπεδο και διαρκεί μόνο όσο
  η μπάλα διασχίζει το nip (~2·√(Rw²−(Rw−δ)²) ≈ 40 mm διαδρομή).
- Η κατεύθυνση εξόδου ορίζεται από τη γεωμετρία (centerline), όχι από
  λεπτή ισορροπία τριβών.

## Transport speed budget (με το πραγματικό μοτέρ — προς μέτρηση στη Phase 3)

Πραγματικό μοτέρ (επιβεβαιωμένο από specs χρήστη, 2026-07-10):

```text
GB37Y3530-12V-251R, gear 43.8:1, encoder Hall 16/700 CPR
No-load speed    251 RPM ±10%  = 26.3 rad/s
Stall torque     18 kg·cm      = 1.77 N·m
Stall current    7 A (driver: BTS7960/TB6612 ανά κανάλι)
```

Η ράμπα καταλήγει στο basket floor top z=0.128 m:

```text
v_min χωρίς απώλειες      √(2·9.81·0.128) ≈ 1.59 m/s
v_target με απώλειες      ~2.0 m/s

Surface speed = ω · Rw (ω_load = ω0·(1 − T/T_stall)):
  26.3 rad/s × 0.060 m = 1.58 m/s   free-run — οριακά στο v_min
  ~20  rad/s × 0.060 m = 1.20 m/s   υπό φορτίο λαβής (~7.5 N traction)
  μεγαλύτερο Rw ΔΕΝ σώζει: +Rw ⇒ +torque demand ⇒ droop, και ⌀>120
  συγκρούεται με τα cheeks
```

**Συμπέρασμα**: το momentum-climb στο z=0.128 ΔΕΝ είναι εφικτό με αυτό το
μοτέρ σε λογικό μέγεθος τροχού. Αποδεκτό υπό την transport φιλοσοφία — η
ανύψωση δεν είναι ευθύνη του release. Η Phase 3 μετρά το πραγματικό
έλλειμμα και επιλέγει από τα mitigations, με σειρά προτίμησης:

```text
1. Feed-onto-ramp: nip x τοποθετημένο ώστε η επαφή των τροχών να
   συνεχίζεται πάνω από την αρχή της ράμπας (η μπάλα σπρώχνεται, δεν
   εκτοξεύεται· ~40 mm ενεργής διαδρομής επαφής).
2. Χαμήλωμα hopper entry / basket handoff (αλλαγή ράμπας).
3. Rw 0.070 + μετατόπιση cheeks (τελευταία επιλογή — αγγίζει το funnel).
```

Nominal: **Rw=0.060 m, ω setpoint ±25 rad/s, joint effort limit 1.77 N·m,
ω cap 26.3 rad/s** — έτσι το stall/jam στο sim αναπαράγει το πραγματικό
droop του μοτέρ.

### Rejected-for-now high-speed option: JGB37-3530-1000

Το JGB37-3530-1000 (12V, 10:1, ~1000 RPM no-load / ~800 RPM rated) δίνει
πολύ υψηλότερη ταχύτητα αλλά κόβει δραματικά το torque:

```text
Rw=0.060 m

251 RPM motor:
  26.3 rad/s × 0.060 = 1.58 m/s
  stall 18 kg·cm = 1.77 N·m ≈ 29 N tangential / wheel

1000 RPM / 10:1 motor:
  800 RPM rated ≈ 83.8 rad/s × 0.060 = 5.0 m/s
  rated 0.38 kg·cm = 0.037 N·m ≈ 0.62 N tangential / wheel
  stall 1.52 kg·cm = 0.149 N·m ≈ 2.5 N tangential / wheel
```

Για `capture -> transport -> guide -> hopper`, το ζητούμενο είναι ελεγχόμενη
λαβή με torque reserve, όχι launcher-like surface speed. Άρα το 1000 RPM
μοτέρ **δεν μπαίνει ως default intake motor**. Μπορεί να μείνει ως μελλοντικό
high-speed experiment μόνο αν η Phase 3 δείξει ότι χρειαζόμαστε διαφορετικό
handoff μηχανισμό και όχι απλώς feed-onto-ramp.

## Actuation

```text
Joints      intake_wheel_left_joint, intake_wheel_right_joint
            (continuous, axis 0 0 1, ένα ανά τροχό)
Έλεγχος     δύο velocity interfaces στο ros2_control, κοινό setpoint
            αντίθετου πρόσημου: ω_left = -ω, ω_right = +ω ώστε οι
            εσωτερικές όψεις να κινούνται προς -x (rearward)
Env         COLLECTOR_INTAKE_WHEEL_SPEED (rad/s, default 25)
Hardware    2 × GB37Y3530-12V-251R gear motor με encoder (ίδιο με τον
            παλιό lift wheel) — ο controller στέλνει ένα κοινό μέτρο
            ταχύτητας, όπως ο πραγματικός driver με δύο κανάλια
Effort/ω    joint effort limit 1.77 N·m (stall torque), velocity limit
            26.3 rad/s (no-load) — το stall/jam στο sim γίνεται φυσικά
            ρεαλιστικό (βλ. Transport speed budget)
Jam metric  per-wheel: |joint velocity| καταρρέει ενώ υπάρχει ενεργό
            contact → stall/jam στο analyzer (αντιστοιχεί στο encoder-based
            jam detection του πραγματικού collector)
```

## Ramp entry προσαρμογές

- `INTAKE_LIP_RAISE_M` → 0 (το lip-as-backstop δεν χρειάζεται· κρατάμε τη
  μεταβλητή για sweep — μη-μηδενικό lip ίσως βοηθά το πρώτο άγγιγμα).
- Το ramp profile (clear zone → knee → end) μένει ως έχει· το entry πρέπει
  να ξεκινά ΠΙΣΩ από το nip plane ώστε η μπάλα να πατά στη ράμπα τη στιγμή
  που δέχεται την ώθηση.
- Ramp πλάτος 180 mm: πρέπει να στενέψει ή να κοπεί τοπικά γύρω από τους
  τροχούς αν υπάρχει τομή (έλεγχος Φάσης 1).

## Instrumentation & acceptance

Contact sensors: ένα ανά τροχό, δεμένα στα υπάρχοντα bridges
`roller_contact_0` (left) και `roller_contact_1` (right), με το δυναμικό
fail-loud binding του `generate_robot_urdf.py`.

Bench: `scripts/sim_debug/run_native_intake_sweep.sh` με νέους sweep axes:

```text
INTAKE_WHEEL_GAP_M, INTAKE_WHEEL_RADIUS_M, INTAKE_NIP_X_M,
INTAKE_SWEEP_WHEEL_SPEEDS, INTAKE_SWEEP_DRIVE_SPEEDS
```

Criteria (από `docs/intake-concept-decision-el.md` — transport concept):

```text
Required:
- confirmed contact with both rollers (roller_contact_0 ΚΑΙ _1)
- successful capture through the wheel throat
- positive inward transport through the intake
- no stall or jam
- ramp-entry crossing
- hopper-entry or ramp-crest crossing
- repeatable success in at least 4/5 runs

Preferred:
- transport speed >= selected target
- contact duration within expected range
- force_p95 below selected threshold
- successful collection from lateral offsets
- successful collection across drive-speed variations
```

Το "positive vertical velocity at release" του παλιού concept ΔΕΝ
μεταφέρεται — ήταν απαίτηση του launch model.

Απόδειξη αντικατάστασης: head-to-head στο ίδιο bench απέναντι στο καλύτερο
καταγεγραμμένο top-roller baseline (7/7 required case του impulse sweep,
release 0.133 m/s, no crest) — το dual-wheel πρέπει να περνά τα νέα required
συν το transport-speed target.

## Φάσεις υλοποίησης (ακολουθούν το Concept Validation Plan)

```text
0. Γεωμετρία + actuation: xacro/generate scripts, 2 velocity joints,
   offline SDF verification, counter-rotation σε /joint_states.
   Υλοποίηση με xacro args (enable_funnel / enable_ramp) ώστε οι
   validation phases να τρέχουν με επιλεκτικά ενεργή γεωμετρία.
1. Phase 1 — dual-wheel throat only (funnel/ramp off):
   capture + powered transport.
2. Phase 2 — funnel + wheels: centering, off-axis capture.
3. Phase 3 — wheels + ramp: transport onto the ramp, μέτρηση του
   πραγματικού transport-speed target.
4. Phase 4 — full intake: collection στο hopper (basket beams).
5. Operating envelope: lateral offset, approach speed, gap tolerance,
   ball compression, friction — 4/5 ανά συνθήκη.
```

Κάθε phase χρησιμοποιεί το υπάρχον bench harness και γράφει
`release_criteria.json` ανά run· αποτυχία phase σταματά την πρόοδο στην
επόμενη (fail-fast, όπως το stop/continue gate του bench report).

Κάθε βήμα καταγράφεται στο `docs/intake-debug-log-el.md` (hypothesis /
result / status) το ίδιο turn με την αλλαγή.

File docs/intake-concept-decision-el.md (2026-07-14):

# Intake concept decision

Ημερομηνία: 2026-07-10

## Απόφαση

Σταματάμε να επενδύουμε στο τρέχον single top-roller + scoop concept ως κύρια
κατεύθυνση για το intake. Η λύση αποδείχθηκε υπερβολικά ευαίσθητη στη
γεωμετρία και στην ταχύτητα επαφής. Αυτό σημαίνει ότι ακόμη κι αν βρεθεί
στενό simulation sweet spot, είναι πιθανό να είναι ευθραυστο στην πραγματική
χρήση.

Η επόμενη κύρια κατεύθυνση είναι dual-wheel / dual-roller intake concept, με
ελεγχόμενο pinch και προβλέψιμη μεταφορά της μπάλας προς τη ράμπα και το
hopper.

Σε αντίθεση με το single top-roller concept, η δημιουργία του pinch, η
προώθηση της μπάλας και η καθοδήγησή της διαχωρίζονται σε ανεξάρτητες
λειτουργίες.

## Evidence

Η απόφαση βασίζεται στο deterministic Gazebo intake bench και στο report:

```text
docs/intake-bench-sweep-report-el.md
```

Κύρια ευρήματα:

- Το `roller_z` ελέγχει αν υπάρχει roller-ball contact, αλλά το χρήσιμο εύρος
  είναι στενό.
- Η μείωση `lip_height` βοήθησε να εμφανιστεί release-like συμπεριφορά, αλλά
  δεν έλυσε τη σταθερότητα.
- Μετά το split `front_lip_contact` / `ramp_guide_contact`, φάνηκε ότι το
  front lip δεν ήταν πλέον ο blocker.
- Τα clear-zone sweeps έδειξαν ότι η ράμπα δεν είναι ο επόμενος κύριος
  περιορισμός.
- Το impulse-generation sweep έδειξε ότι:
  - χαμηλότερο drive speed έχασε τελείως roller contact,
  - υψηλότερο roller speed αύξησε contact activity αλλά έδωσε λάθος
    κατεύθυνση release,
  - το μόνο 7/7 required case είχε πολύ χαμηλή release speed και no crest.

Το failure mode δεν βελτιώθηκε ουσιαστικά μετά από διαδοχικά στοχευμένα
experiments. Αυτό ενεργοποιεί το stop / continue gate:

```text
Continue?
  No, reconsider concept.
```

## Why Not Keep Tuning

Το single top-roller setup ζητάει ταυτόχρονα:

- αρκετή αντίσταση ώστε ο roller να μεταδώσει κίνηση,
- όχι τόσο πολύ pinch ώστε να γίνει conveyor ή jam,
- σωστή release κατεύθυνση,
- αρκετή release speed,
- ανεκτικότητα σε πραγματικές αποκλίσεις μπάλας, foam, τριβής, ταχύτητας και
  επιφάνειας.

Το simulation έδειξε ότι αυτά δεν συνυπάρχουν εύκολα στο τρέχον concept. Αυτό
είναι κόκκινη σημαία για πραγματικό μηχανισμό, όπου οι ανοχές και οι φθορές θα
είναι χειρότερες από το deterministic bench.

Το βασικό πρόβλημα δεν είναι ότι δεν βρέθηκε ακόμη το σωστό configuration,
αλλά ότι δεν εμφανίστηκε αρκετά μεγάλο operating envelope ώστε η λύση να
θεωρείται ανθεκτική σε πραγματικές αποκλίσεις.

Engineering decision:

```text
A concept that only works inside a narrow simulation sweet spot is not
considered an acceptable production direction for this project.
```

## Λειτουργική φιλοσοφία

Το προηγούμενο concept είχε στόχο:

```text
bite -> impulse -> launch -> ramp
```

Το νέο concept περιγράφεται ως:

```text
capture -> transport -> guide -> hopper
```

Η μπάλα δεν εκτοξεύεται· συλλαμβάνεται, μεταφέρεται ενεργά μέσα από το wheel
throat και καθοδηγείται προς το hopper. Κάθε στάδιο αξιολογείται χωριστά.

## Next Concept Direction

Το dual-wheel / dual-roller concept πρέπει να δοκιμαστεί με στόχο:

- controlled pinch ανάμεσα σε δύο ενεργές επιφάνειες,
- προβλέψιμη μεταφορά της μπάλας μέσα από το wheel throat,
- ανεξάρτητη λειτουργία funnel, rollers και ramp,
- δυνατότητα ρύθμισης wheel gap/compression χωρίς αλλαγή της υπόλοιπης
  γεωμετρίας,
- repeatability σε 4/5 runs πριν θεωρηθεί candidate.

Προτεινόμενα πρώτα simulation criteria:

```text
Required:
- confirmed contact with both rollers
- successful capture through the wheel throat
- positive inward transport through the intake
- no stall or jam
- ramp-entry crossing
- hopper-entry or ramp-crest crossing
- repeatable success in at least 4/5 runs

Preferred:
- transport speed >= selected target
- contact duration within expected range
- force_p95 below selected threshold
- successful collection from lateral offsets
- successful collection across drive-speed variations
```

Σημείωση: το παλιό required "positive vertical velocity at release" ήταν
απαίτηση του launch concept και δεν μεταφέρεται στο transport concept. Η
ανύψωση είναι πλέον ευθύνη του guide/ramp σταδίου, όχι του release.

## Initial Dual-Wheel Architecture

Το πρώτο prototype θα ακολουθήσει την απλούστερη δυνατή αρχιτεκτονική.

Mechanism:

- δύο side rollers
- κατακόρυφοι άξονες περιστροφής
- οριζόντιο pinch
- συμμετρικό funnel για centering
- guide ramp προς το hopper

Drive train:

- δύο ίδια μοτέρ
- ένα μοτέρ ανά roller
- ίδια ονομαστική ταχύτητα
- αντίθετη φορά περιστροφής
- ίδιο torque/current limit
- κοινό emergency stop
- coordinated jam handling

Δεν χρησιμοποιείται αρχικά κοινό μοτέρ με γρανάζια.
Ο στόχος είναι πρώτα να αποδειχθεί η μηχανική αρχή και μετά να εξεταστεί
πιθανή απλοποίηση του drivetrain.

## Concept Validation Plan

Το νέο concept θα επικυρωθεί σταδιακά.

```text
Phase 1
  Dual-wheel throat only
  Goal: Validate capture and powered transport.

Phase 2
  Funnel + dual wheels
  Goal: Validate ball centering and off-axis capture.

Phase 3
  Dual wheels + ramp
  Goal: Validate transport onto the ramp.

Phase 4
  Full intake
  Goal: Validate complete collection into the hopper.
```

## Operating Envelope Validation

Η αποδοχή του νέου concept δεν θα βασιστεί σε μία επιτυχημένη δοκιμή.

Το concept πρέπει να αποδείξει ότι λειτουργεί σε εύρος πραγματικών συνθηκών.

Representative variations:

- lateral ball offset
- robot approach speed
- wheel gap tolerance
- ball compression variation
- friction variation

Success criterion:

```text
At least 4 successful collections out of 5 runs for each representative
condition.
```

## Branch Plan

Αυτό το branch κρατάει:

- το deterministic bench,
- τα instrumentation εργαλεία,
- τα release criteria,
- την τεκμηρίωση της απόφασης.

Νέο branch για την επόμενη μηχανική κατεύθυνση:

```text
feat/dual-wheel-intake-concept
```

Το νέο branch πρέπει να ξεκινήσει από το current work, όχι από παλιό main,
ώστε να κληρονομήσει το bench και τα measurement tools.

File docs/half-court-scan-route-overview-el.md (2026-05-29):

# Half-Court Scan And Route Overview

Last checked: 2026-05-27

This document defines the first mapping and route-planning approach for the tennis robot collector. The goal is to avoid reactive back-and-forth movement by scanning one half of the court, building a temporary ball map, planning a collection route, and refreshing that map during collection.

The intended first hardware path uses a low-mounted Waveshare/Slamtec RPLIDAR C1 360-degree 2D LiDAR for real-time court/obstacle mapping, with the top-mounted OAK-D S2 as the primary tennis-ball detector:

- Low 360-degree LiDAR sweep for court boundaries, obstacle edges, net/fence/wall clearance, people/bags, route costmaps, and shadow zones.
- Top OAK-D RGB image for tennis-ball detection and color/shape classification.
- OAK-D stereo depth for distance, clusters, and balls in LiDAR shadow zones.
- IMU as part of future pose estimation.
- Wheel encoders, when the mobile base is selected, for odometry.

## Strategy

Split collection into two independent court phases:

1. Collect all reachable balls on one side of the net.
2. Move/reset to the other side.
3. Repeat the same scan, route, refresh, and collect loop.

The first implementation does not require full SLAM. It uses court-bounded local mapping:

```text
LiDAR scan + robot pose -> obstacle/cost map + shadow zones in court coordinates
OAK-D RGB/depth + robot pose -> ball positions in court coordinates
```

The LiDAR does not try to be a tennis-ball detector. A 6.7 cm ball is too small and inconsistent for reliable 2D LiDAR returns. Its job is to keep the planner's map fresh without a slow survey phase, and to tell the OAK-D where the scene is blocked, cluttered, or worth a targeted look.

## High-Level Flow

```mermaid
flowchart TD
    A["Start collection command"] --> B["Select court phase"]
    B --> C["Initial half-court scan"]
    C --> D["Build ball map"]
    D --> E["Plan route for visible/reachable balls"]
    E --> F["Collect next ball"]
    F --> G{"Refresh needed?"}
    G -- "No" --> H{"More planned balls?"}
    G -- "Yes" --> I["Local refresh scan"]
    I --> J["Merge observations into ball map"]
    J --> K["Replan remaining route"]
    K --> H
    H -- "Yes" --> F
    H -- "No" --> L{"Other half pending?"}
    L -- "Yes" --> B
    L -- "No" --> M["Collection complete"]
```

## Perception-To-Map Pipeline

```mermaid
flowchart LR
    LIDAR["Low 360-degree LiDAR scan"] --> COST["Obstacle / clearance costmap"]
    LIDAR --> SHADOW["Shadow zones / occluded sectors"]
    RGB["Top OAK-D RGB frame"] --> DET["Visual ball detector"]
    DEPTH["OAK-D stereo depth"] --> RANGE["Depth crop / median range"]
    DET --> VOBS["Visual/depth observations"]
    RANGE --> VOBS
    SHADOW --> LOOK["Targeted OAK-D look/refresh"]
    LOOK --> DET
    POSE["robot pose x/y/yaw"] --> WORLD["Court coordinate projection"]
    VOBS --> WORLD
    WORLD --> MAP["Ball map"]
    POSE --> COST
    MAP --> ROUTE["Route planner"]
    COST --> ROUTE
```

The simulated code already has the core projection shape in `controllers/ball_detector/perception.py`:

```text
BallDetection -> BallObservation -> robot XY -> world/court XY
```

The physical robot should preserve this contract even if the camera detector changes from HSV thresholding to a neural model later. LiDAR should feed traversability, clearance, and shadow-zone data; OAK-D observations should feed the ball map.

## Ball Map State

```mermaid
stateDiagram-v2
    [*] --> detected
    detected --> planned
    planned --> approaching
    approaching --> collected
    approaching --> missing
    approaching --> blocked
    missing --> detected: refresh scan sees it again
    blocked --> planned: obstacle clears / route changes
    collected --> [*]
```

Minimum fields for the first implementation:

| Field | Purpose |
|---|---|
| `id` | Stable temporary ball identity. |
| `x_m`, `y_m` | Court position estimate. |
| `confidence` | Detection reliability or freshness score. |
| `last_seen_s` | Helps age out stale detections. |
| `state` | `detected`, `planned`, `approaching`, `collected`, `missing`, or `blocked`. |
| `phase` | Court side / half-court ownership. |

## Route Selection

The first route planner can be greedy instead of a perfect TSP solver. It should choose the next reachable ball with the lowest weighted cost:

```text
cost = path_distance
     + turn_cost
     + stale_detection_penalty
     + obstacle_penalty
     + edge_penalty
     + lidar_clearance_penalty
     - confidence_bonus
```

With RPLIDAR C1 installed, `obstacle_penalty`, `edge_penalty`, and `lidar_clearance_penalty` should come from the 2D costmap instead of camera-only heuristics. The route should be recalculated after a refresh scan, after a blocked route, or after a missing ball.

## Sensor Roles

| Sensor | Main question | Algorithm output |
|---|---|---|
| Waveshare/Slamtec RPLIDAR C1 low 360-degree LiDAR | Where can the robot move safely, and what areas are blocked from view? | Occupancy/cost map, wall/net/fence clearance, obstacle inflation, shadow zones. |
| Top OAK-D S2 | Where are the tennis balls? | Ball detections, RGB-D observations, depth, bearing, ball map. |
| Encoders + IMU | Where is the robot now? | Odometry and pose prediction/correction. |

The LiDAR is not the primary tennis-ball detector. A 2D scan can miss balls, merge them into nearby geometry, or shadow everything behind the first object in the scan. The OAK-D stays responsible for ball detection, while the LiDAR keeps the obstacle map live.

## Scan Policy

```mermaid
flowchart TD
    A["Initial scan"] --> B["2-4 scan viewpoints per half"]
    B --> C["Map visible balls"]
    C --> D["Plan route"]
    D --> E["Collect batch"]
    E --> F{"Batch size reached?"}
    F -- "Yes" --> G["Short refresh from current pose"]
    F -- "No" --> H{"Target lost / obstacle?"}
    H -- "Yes" --> G
    H -- "No" --> E
    G --> I["Merge + replan remaining balls"]
    I --> E
```

Recommended starting defaults:

| Parameter | Initial value |
|---|---:|
| Initial scan viewpoints per half | 2-4 |
| Refresh interval | Every 3-5 collected balls |
| Missing-ball retries | 2 |
| Minimum detection confidence | Start permissive, tighten after real camera tests |
| Replan trigger | Refresh scan, blocked path, target missing, safety stop |

## Realistic Ball Distribution

The simulator and Webots ball generator should not use a purely uniform scatter by default. In a physical court, more balls tend to settle near:

- the net, after short/failed returns and balls rolling inward;
- the back court or wall/fence behind the baseline;
- with fewer balls staying in the open middle of the court.

The first biased randomizer uses this approximate mix:

| Zone | Approx. share |
|---|---:|
| Near net | 46% |
| Back court / baseline wall side | 36% |
| Service-line / transition area | 12% |
| Uniform outliers | 6% |

This distribution is still deterministic by seed, but it makes route planning tests more realistic because the planner must handle clustered balls instead of evenly spaced targets.

## First Implementation Scope

For the first implementation in the browser route simulator:

1. Add a two-phase court mode.
2. Generate balls across both halves.
3. Plan phase A and phase B separately.
4. Add explicit phase scan and refresh scan events.
5. Keep telemetry for phases, scans, replans, distance, blocked balls, and collection order.
6. Add a LiDAR obstacle/shadow-zone mode and compare camera-only planning against OAK-D ball detection plus live LiDAR costmaps.

For benchmark validation:

1. Run 100 deterministic random scenarios with 40 balls each.
2. Measure average collection time, distance, collectable rate, replans, and scan events.
3. Estimate miss risk for balls close to net, wall/fence, or obstacles.
4. Compare realistic ball bias against uniform scatter.
5. Compare `rescan_every`, travel speed, safety buffer, and candidate-window settings.
6. Export per-decision candidate rows with `--training-out` for a future next-ball ranking model.

The first useful machine-learning dataset is a learning-to-rank table. Each planning decision writes one row per candidate ball:

```text
robot pose + ball pose + route/risk features -> selected
```

This lets a model learn the planner's current policy first. Later, physical-run outcomes can replace or augment the label with real success/failure and pickup time.

For the Webots/physical controller after that:

1. Publish detected balls in court coordinates.
2. Add a persistent ball map.
3. Feed the current map into a route planner.
4. Convert the selected next ball into the existing `scan -> align -> approach -> capture` state machine.

## Open Decisions

| Decision | Default for now |
|---|---|
| Side order | Start on the left/west half in simulation. |
| Net crossing | Treat halves as independent phases; do not plan through the net. |
| Full SLAM | Defer until court-line correction plus odometry is insufficient. |
| LiDAR | Use the Waveshare/Slamtec RPLIDAR C1 mounted low on the robot for 360-degree obstacle/court mapping and shadow-zone generation, not primary ball detection. |
| Perfect route solver | Defer; use greedy route with penalties and refresh scans. |

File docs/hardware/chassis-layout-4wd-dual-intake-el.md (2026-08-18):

# Τρέχον σχέδιο chassis — 4WD και dual-wheel intake

Ημερομηνία baseline: 2026-08-16

Αυτό είναι το ενεργό μηχανολογικό layout του prototype. Αν υπάρχει διαφορά
με παλαιότερο Concept A, 2WD/caster σχέδιο ή cut list, υπερισχύει αυτό το
έγγραφο μαζί με το URDF και τα ενεργά mechanism specs.

Current 4WD and dual-wheel layout

## 1. Κλειδωμένη αρχιτεκτονική

- Επίπεδο chassis `920 × 580 mm`, χωρίς κλίση.
- Τέσσερις ίδιοι κινητήριοι τροχοί `170 × 80 mm`, δύο ανά πλευρά.
- 4WD skid-steer χωρίς caster.
- Wheelbase `660 mm`: άξονες drive στο `x=±330 mm`.
- Wheel centres στο `y=±350 mm`, άρα συνολικό εξωτερικό πλάτος περίπου
  `780 mm` μαζί με τα ελαστικά.
- Τέσσερα FIT0403, ένα ανά drive wheel. Στο πρώτο prototype τα δύο μοτέρ της
  κάθε πλευράς συνδέονται παράλληλα σε ένα BTS7960.
- Dual-wheel side-pinch intake μπροστά: δύο κάθετοι intake τροχοί, ένα μοτέρ
  ανά τροχό, αντίθετης φοράς.
- Βυθισμένο, αφαιρούμενο basket v2.1 στο κέντρο/μπροστά του chassis.
- Μπαταρία χαμηλά και πίσω από το basket, κοντά στον διαμήκη άξονα.

Οι αριθμητικές τιμές αναφοράς προέρχονται από
`ros2_ws/src/tennis_robot/urdf/tennis_robot.urdf.xacro`. Η γεωμετρία intake
και basket ορίζεται αντίστοιχα στα:

- `docs/mechanism/dual-wheel-intake-design-el.md`
- `docs/mechanism/basket-bin-redesign-spec-el.md`
- `cad/basket-bin-v2/params.scad`

## 2. Drive modules

Κάθε γωνία έχει αφαιρούμενο motor pod για FIT0403 και τροχό HPI Baja 5B:

```text
rear-left      x=-330 mm, y=+350 mm
rear-right     x=-330 mm, y=-350 mm
front-left     x=+330 mm, y=+350 mm
front-right    x=+330 mm, y=-350 mm
shaft height   z=85 mm από το έδαφος
```

Το `y=±350 mm` είναι το κέντρο του τροχού, όχι η άκρη του chassis. Οι τροχοί
είναι εξωτερικοί της πλάκας. Όλοι οι άξονες πρέπει να έχουν το ίδιο ύψος ώστε
να πατούν και οι τέσσερις τροχοί χωρίς να στρεβλώνεται η βάση.

Μη χρησιμοποιήσεις ακόμη το SVG ως drilling template. Πριν ανοίξουν τελικές
τρύπες M5, πρέπει να μετρηθούν πάνω στα πραγματικά `19-00037912` motor mounts:

- απόσταση και διάμετρος οπών,
- θέση shaft ως προς την επιφάνεια στήριξης,
- clearance του μοτέρ και του encoder connector,
- clearance του 12→24 mm wheel adapter και του ελαστικού.

## 3. Intake και basket interface

Η ροή της μπάλας είναι:

```text
wide funnel
  -> δύο intake wheels / side pinch
  -> ramp + receiving chute
  -> basket entry hood
  -> αφαιρούμενο basket v2.1
```

Το intake δεν είναι ο παλιός οριζόντιος wide roller. Οι δύο κύριοι intake
τροχοί έχουν κατακόρυφους άξονες, ακτίνα `60 mm`, ύψος `80 mm`, nominal gap
`56 mm`, nominal nip `x=540 mm` και tilt `35°` στο τρέχον URDF baseline.
Κάθε τροχός χρειάζεται ανεξάρτητο μοτέρ και ενδοτική πλευρική στήριξη.

Το basket έχει εσωτερικό `400 × 280 mm`, εκτείνεται περίπου από `x=20` έως
`x=420 mm` και αφαιρείται προς τα πάνω. Μην τοποθετηθεί μόνιμη τραβέρσα πάνω
από το άνοιγμα αφαίρεσης. Το entry hood μένει στο chassis και ανοίγει ή
αφαιρείται πριν σηκωθεί το basket.

## 4. Electronics και καλώδια

- Mega/perfboard και logic connectors σε προστατευμένο, προσβάσιμο tray.
- BTS7960 και 40A relay εκτός κλειστού κουτιού, με αερισμό.
- High-current καλώδια εκτός perfboard, σύμφωνα με
  `docs/hardware/motion-perfboard-wiring-el.md`.
- Δύο ανεξάρτητα cable looms drive, ένα ανά πλευρά, ώστε τα εμπρός/πίσω μοτέρ
  να αποσυνδέονται χωρίς να λυθεί όλο το robot.
- Encoder και sensor καλώδια μακριά από `M+`/`M-` και relay wiring.
- Πρόβλεψη service loop για τα τέσσερα drive encoders και τα δύο intake motors.

## 5. Τι μπορεί να κοπεί τώρα

Μπορεί να σημαδευτεί και να κοπεί μόνο το εξωτερικό περίγραμμα `920 × 580 mm`,
εφόσον έχει επιλεγεί οριστικά το υλικό/πάχος. Το sim χρησιμοποιεί πλάκα
`14 mm`. Η παλιότερη λίστα `760 × 430 × 21 mm` έχει αρχειοθετηθεί και δεν
είναι έγκυρη για κατασκευή.

Πριν από εσωτερικά ανοίγματα ή τρύπες απαιτούνται πραγματικές μετρήσεις για:

1. τα τέσσερα motor mounts,
2. το βυθισμένο basket και το flange του,
3. τα intake carriages και το funnel,
4. battery straps και έξοδο μπαταρίας,
5. Mega/perfboard, BTS7960, relay και fuse holders,
6. lidar mast και OAK-D bracket.

Η σειρά κατασκευής είναι: dry-fit drive pods → έλεγχος τεσσάρων επαφών στο
έδαφος → basket opening → intake alignment → battery/electronics → sensors.

## 6. Αρχειοθετημένα σχέδια

Τα 2WD/caster, pitched-chassis, single-wide-roller και 760×430 σχέδια βρίσκονται
στο `docs/archive/mechanical/`. Είναι χρήσιμα μόνο για ιστορικό αποφάσεων και
δεν πρέπει να χρησιμοποιούνται για κοπή, διάτρηση ή παραγγελία εξαρτημάτων.

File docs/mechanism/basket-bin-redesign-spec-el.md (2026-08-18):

# Καλάθι v2: βυθισμένο αφαιρούμενο μπιν — design spec

Σκοπός: αντικατάσταση του scoop-era καλαθιού με χαμηλό, βυθισμένο,
αφαιρούμενο μπιν συμβατό με το bench-proven dual-wheel intake
(debug-log #41-#44). Λύνει τη συγκράτηση (το 3mm lip δεν κρατά γεμάτο
καλάθι), τη θέση της μπαταρίας, και το lidar-mast conflict.

Αποφάσεις χρήστη (2026-07-12): χωρητικότητα ~50 μπάλες, αφαιρούμενο μπιν,
συγκράτηση = προς συζήτηση → επιλέχθηκε βυθισμένο πάτωμα, lidar mast ΕΚΤΟΣ
εσωτερικού — μόνο στο πάνω πλαίσιο, εξωτερικά.

**Αναθεώρηση v2.1 (log #46)**: το rolling-ball sweep έδειξε ότι το lip
0.055 περνούσε μόνο στην κόψη (drive 0.12· στο 0.14+ η μπάλα έχανε 2-5mm
ύψους και σφήνωνε στο wedge). Τελικές τιμές: **lip 0.045, πάτωμα 0.025** →
απαίτηση εισόδου 0.078 (πραγματικό περιθώριο σε drive 0.12-0.25),
συγκράτηση 20mm, διάκενο εδάφους 20mm. Επιπλέον ο analyzer απέκτησε τίμιο
κριτήριο hopper-entry (τελική θέση ΜΕΣΑ στο μπιν, OR με crest crossing —
με χαμηλό lip το pivot ύψος συμπίπτει με το crest plane και το «crossing»
δεν καταγραφόταν παρότι η μπάλα ήταν αποδεδειγμένα μέσα).

Όλα τα ύψη σε **ground frame** εκτός αν σημειώνεται. Chassis plate top =
0.052, base_link 0.045 πάνω από έδαφος.

## 1. Σκληροί περιορισμοί (μετρημένοι — μην ξανασυζητηθούν χωρίς νέα δεδομένα)

| Περιορισμός | Τιμή | Πηγή |
|---|---|---|
| Ενεργειακό ταβάνι κέντρου μπάλας στο χείλος | ~0.093 | log #41 Run B/C |
| Μέγιστο ύψος lip εισόδου | 0.060 (τρέχον: 0.045) | ταβάνι − 0.033 |
| Θέση lip / μπροστινή ακμή πατώματος | x = 0.425 / 0.42 | winning jump #41 |
| Jump profile v2.1 | 0.500 → (0.465, 0.020) → (0.425, 0.045) | rolling-ball log #46 |
| Basket IR beam pair | x=0.445, z=0.0705 | midpoint of receiving chute |
| Επιβεβαιωμένη τελική θέση target με load 25 | x=0.400, z=0.0666 | low-transition run |

## 2. Μπιν (αφαιρούμενο, βυθισμένο)

### Εσωτερικό landing tray για διαχείριση φορτίου

Η wheel-only βολή χρειάζεται ελεύθερη ζώνη εισόδου όταν το μπιν έχει πάνω
από μία στρώση. Προστίθεται εσωτερικό συρμάτινο tray μόνο μέσα στο καλάθι:

- αρχή στο μπροστινό όριο `x=0.42`, top `z=0.035`, flush με το retention lip,
- τέλος στο `x=0.28`, top `z=0.025`, flush με το κύριο πάτωμα,
- run `0.14 m`, rise `0.010 m`, κλίση περίπου `4.1°` προς τα πίσω,
- παράμετροι sim: `BASKET_MANAGEMENT_RUN_M` και
  `BASKET_MANAGEMENT_RISE_M` (`rise=0` για A/B test).

Το tray δεν συμμετέχει στην εκτόξευση και δεν ακουμπά την μπάλα πριν από το
nip. Παραλαμβάνει τη μπάλα μόνο αφού περάσει το άνοιγμα και μετακινεί το
αποθηκευμένο φορτίο προς το πίσω τμήμα του μπιν.

### Μπροστινή κεκλιμένη υποδοχή

Μια κεντρική συρμάτινη προέκταση συνεχίζει το landing tray προς τους τροχούς,
ώστε η βολή να χρειάζεται μόνο μικρό ελεύθερο διάστημα και να μην εξαρτάται
από το ύψος της πρώτης στρώσης μπαλών:

- πίσω άκρο `x=0.42`, top `z=0.035`, χωρίς σκαλοπάτι από το management tray,
- μπροστινό άκρο `x=0.47`, top `z=0.040`,
- run `0.050 m`, rise `0.005 m`, πλάτος `0.180 m`,
- παράμετροι sim: `BASKET_RECEIVER_RUN_M` και `BASKET_RECEIVER_RISE_M`,
- `run=0` αφαιρεί την υποδοχή για A/B test.

Το basket confirmation beam περνά εγκάρσια από το μέσο της υποδοχής στο
`x=0.445`, ground `z=0.0705`, δηλαδή στο κέντρο μιας μπάλας που κυλά πάνω της.
Οι πομποδέκτες στερεώνονται στο σασί και η δέσμη περνά μέσα από το αφαιρούμενο
πλέγμα.

### Entry hood (validated στο load 45 — log #54-#56, sim default)

Πάνω από την υποδοχή και το μπροστινό άκρο του μπιν τοποθετείται
σασί-μόνιμη κουκούλα από πλέγμα, που έλυσε τις δύο αστοχίες του γεμάτου
καλαθιού (διαφυγές φορτίου στην είσοδο + απόρριψη της εισερχόμενης μπάλας
πάνω από τον σωρό):

- **Roof** (κεκλιμένο πλέγμα, πλάτος 0.180): πίσω άκρο `x=0.38`
  (overhang 40mm ΜΕΣΑ από το όριο του μπιν), κάτω επιφάνεια ground
  `z=0.120`· μπροστινό άκρο `x=0.47`, κάτω επιφάνεια `z=0.135`.
- **Cheeks**: δύο πλαϊνά φύλλα στα `y=±0.09` κατά μήκος της υποδοχής,
  από την επιφάνειά της ως το roof — κλείνουν το πλάι του καναλιού.
- Παράμετροι sim (πλέον defaults): `BASKET_HOOD_REAR_OVERHANG_M=0.040`,
  `BASKET_HOOD_REAR_CLEARANCE_Z_M=0.120`,
  `BASKET_HOOD_FRONT_CLEARANCE_Z_M=0.135` (`overhang=0` αφαιρεί το hood
  για A/B).
- Το rear clearance 0.120 είναι κρίσιμο: στο 0.105 η target απορριπτόταν
  (4/8)· στο 0.120 πέρασε 5/5 loaded gate. Μπάλα που κυλά στην υποδοχή
  (κορυφή ~0.104) χωρά κάτω από το roof με ~16mm περιθώριο.
- **Κατασκευαστικά**: το hood ΔΕΝ είναι μέρος του αφαιρούμενου μπιν —
  βιδωτό/ανακλινόμενο στο σασί, ώστε να αφαιρείται πρώτο και το μπιν να
  σηκώνεται μετά ελεύθερα (βλ. `cad/basket-bin-v2/README.md`).

- **Εσωτερικό**: x **0.02 … 0.42** (μήκος 0.40), y **±0.14** (πλάτος 0.28).
- **Πάτωμα**: top **0.025** (βυθισμένο 27mm κάτω από το plate top μέσα από
  άνοιγμα στο σασί). Πάχος πάτου 5mm → κάτω εξωτερική επιφάνεια 0.020 =
  **20mm διάκενο εδάφους** (νέο χαμηλότερο σημείο του ρομπότ· λοξή/
  στρογγυλεμένη μπροστινή ακμή ως skid).
- **Συγκράτηση**: εξωτερικό άκρο 0.040 − πάτωμα 0.025 = **15mm** (ταχύτητα
  διαφυγής ~0.54 m/s, έναντι 3mm/0.24 m/s στο scoop-era καλάθι).
- **Τοίχοι**: έως **0.25** (πλήρως κάτω από lidar plane 0.498· ύψος 22cm
  από το πάτωμα). Πίσω τοίχος στο x=0.02, πλαϊνοί στο y=±0.14, μπροστά ο
  «τοίχος» είναι η πλάτη του jump (η εξωτερική επιφάνεια του ramp sheet).
- **Χωρητικότητα**: 0.40×0.28×0.22 ≈ 24.6L ≈ 100+ μπάλες θεωρητικά —
  διπλάσιο περιθώριο από τον στόχο 50 (≈7.5L όγκος μπαλών).
- **Αφαίρεση**: προς τα πάνω· λαβές στα πλαϊνά χείλη. Το μπιν κάθεται σε
  περιμετρικό flange πάνω στην πλάκα (δεν κρέμεται από τον πάτο).
- **Υλικό/δομή (απόφαση χρήστη 2026-07-12)**: **συρμάτινο πλέγμα σε
  σκελετό**, όχι συμπαγές υλικό — όπως τα πραγματικά tennis hoppers.
  Άνοιγμα πλέγματος ≤ 40mm (μπάλα 66mm δεν περνά). Συνέπειες:
  - Βάρος μπιν ~0.5-1kg (αντί 2-3kg συμπαγές) — αμελητέο στη ζυγοστάθμιση.
  - Αποστράγγιση χώματος/νερού από τον βυθισμένο πάτο (20mm από έδαφος).
  - **Sim**: οι συγκρούσεις μένουν συμπαγή boxes (ισοδύναμο για μπάλα
    66mm >> άνοιγμα πλέγματος)· τα visuals αποδίδουν ανοιχτό wire grid 40mm,
    όχι συμπαγείς επιφάνειες.
- **IR beams (λύνεται από το πλέγμα)**: οι αισθητήρες τοποθετούνται στο
  `(0.445, ±0.105, 0.0705)` και κατασκευαστικά μένουν **στο σασί/σκελετό,
  εκτός μπιν (y=±0.15+), και οι δέσμες περνούν ΜΕΣΑ ΑΠΟ το πλέγμα** — το
  μπιν αφαιρείται χωρίς καμία ηλεκτρική σύνδεση. Ευθυγράμμιση δέσμης-
  ανοίγματος (τοπικά μεγαλύτερο μάτι αν χρειαστεί) = λεπτομέρεια OpenSCAD.
  Η μπάλα κόβει τη δέσμη ενώ κυλά στην κεκλιμένη υποδοχή, πριν περάσει στο
  κυρίως καλάθι. Οι αποθηκευμένες μπάλες βρίσκονται πίσω από το `x=0.42` και
  δεν την ξανακόβουν.

## 3. Άνοιγμα σασί

- Άνοιγμα πλάκας: x 0.01 … 0.46 (έως την μπροστινή ακμή — χωρίς κεντρικό
  γεφύρωμα μπροστά: πλάκα στο 0.052 στα x 0.43-0.46 θα εξείχε πάνω από το
  jump sheet και θα ξυνόταν η μπάλα στην είσοδο), y ±0.15. Στο sim το
  άνοιγμα είναι ΠΡΑΓΜΑΤΙΚΟ (πλάκα = 2 πλαϊνές λωρίδες |y| 0.15-0.29 +
  πίσω μπλοκ x −0.46…0.01) ώστε η μπάλα να πατά όντως στο πάτωμα 0.025.
- Περιμετρική ενίσχυση: cross rails εκατέρωθεν (το «middle battery area»
  rail του παλιού 760×430 cut list ΚΑΤΑΡΓΕΙΤΑΙ/μετακομίζει — βλ. §4 και
  `docs/hardware/chassis-layout-4wd-dual-intake-el.md`).

## 4. Battery bay (πίσω deck)

- Μπαταρία χρήστη: 19.8 × 16.6 × 17.0 cm, 6.26kg.
- **Θέση**: x **−0.06 … −0.226** (16.6 κατά x), y κεντραρισμένη
  (19.8 κατά y), πάνω στην πλάκα → κορυφή 0.222 (28cm κάτω από lidar
  plane, εκτός FOV κάμερας).
- Straps + cross rail πίσω από το μπιν (αντικαθιστά τον middle rail).
- **Ζυγοστάθμιση**: 6.26kg με κέντρο x≈−0.14 αντισταθμίζει το μπροστινό
  intake overhang (~3.5-4kg στο x≈+0.5)· γεμάτο μπιν (2.9kg στο x≈0.22)
  σχεδόν ουδέτερο. Πίσω deck που απομένει: x −0.226…−0.46 για ηλεκτρονικά.

## 5. Lidar mast (εκτός εσωτερικού)

- Από (−0.08, 0, 0.498) → **(−0.42, 0, 0.498)**: ιστός στο πίσω πάνω
  πλαίσιο, εξωτερικά του εσωτερικού όγκου. Ύψος/scan plane αμετάβλητα.
- Μόνο TF παράμετρος (`lidar_xyz`) — καμία αλλαγή σε SLAM/survey/extraction.
- Αυτο-σκίαση: αμετάβλητη (μόνο ψηλό στοιχείο η κάμερα στο 0.443, μπροστά).

## 6. Υλοποίηση στο sim (σειρά)

1. `basket.urdf.xacro` v2: μπιν (πάτωμα/τοίχοι) + άνοιγμα σασί
   (το chassis collision παραμένει ενιαίο box — τα fixed links δεν
   συγκρούονται μεταξύ τους· το άνοιγμα είναι κατασκευαστική σημείωση,
   στο sim απλώς το πάτωμα μπαίνει στο 0.025). Xacro defaults:
   `basket_floor_top_z=0.025`, `basket_floor_front_x=0.42`,
   νέο `BASKET_REAR_X_M=0.02`, `BASKET_HALF_WIDTH_M=0.14`,
   `BASKET_WALL_TOP_Z_M=0.25`.
2. Battery box (visual+inertial ~6.3kg) στο πίσω deck — επηρεάζει
   φυσική/CoG στο sim, αξίζει να μπει.
3. `lidar_xyz` → (−0.42, 0, 0.498).
4. Controller constants: BASKET_ZONE (0.02…0.42), BASKET_MIN_BALL_Z = 0.055.
   Με v2.1 floor 0.025 η μπάλα ηρεμεί μέσα στο hopper σε z≈0.058, άρα το sim
   path πρέπει να μετρά και τελική παραμονή μέσα στο bin, όχι μόνο πέρασμα πάνω
   από lip. Το controller κρατά one-shot guard ανά sim ball def ώστε να μη
   διπλομετράει μέχρι να γίνει remove από το `/ball/collected`.
5. Επαλήθευση: offline SDF αριθμητικά → Phase 4 suite (envelope 5 offsets
   + boundary ×5) → retention test (γεμάτο μπιν: spawn 10-20 μπάλες μέσα,
   οδήγηση με στροφές/στάσεις, μέτρηση διαφυγών) → live collect_one.
6. Plywood-cut-list: σημείωση αναθεώρησης (rail μετακίνηση, άνοιγμα
   πλάκας, mast στο πίσω πλαίσιο) — πλήρης αναθεώρηση μαζί με το OpenSCAD.

## 7. Εκτός scope εδώ

- Rolling-ball nip entry (bench campaign, log #44) — ανεξάρτητο, το
  interface (lip/jump) δεν αλλάζει.
- OpenSCAD μοντέλο — **έγινε**: `cad/basket-bin-v2/` (μπιν + hood +
  chassis context, παραμετρικό από αυτό το spec).
- Camera blind zone (ξεχωριστό task).

## 8. Evidence logs για smooth entry και loaded basket

Κάθε intake sweep με διαθέσιμο Gazebo pose log παράγει πλέον:

- `gz_poses.jsonl`: ground-truth timeline για robot, target `ball_*` και
  προφορτωμένες `stored_ball_*`.
- `basket_evidence.json`: machine-readable αποτέλεσμα.
- `basket_evidence.pretty.json`: ίδιο αποτέλεσμα για ανθρώπινο review.

Το authoritative basket PASS δεν είναι το `/ball/collected` event. Απαιτεί
όλα τα παρακάτω από το `analyze_basket_evidence.py`:

1. Η target μπάλα μπήκε στο robot-relative bin volume.
2. Παρέμεινε συνεχόμενα τουλάχιστον 0.75s.
3. Είχε σχετική ταχύτητα <=0.08m/s για τουλάχιστον 0.50s.
4. Υπήρχε ακόμη μέσα στο bin στο τελευταίο pose sample.
5. Παρατηρήθηκε ακριβώς το αναμενόμενο πλήθος `stored_ball_*`.
6. Καμία stored μπάλα δεν έφυγε από το bin.
7. Robot pitch και roll έμειναν εντός ±8deg.

Άμεσο checkpoint/remove της target αποτυγχάνει ρητά στο
`target_retained_at_end`, ακόμη και αν το transport release criteria είναι
6/6. Για τα load runs χρησιμοποιείται `INTAKE_BASKET_LOAD_COUNT=0|15|25|45`.

### 8.1 Effective contact model του πλέγματος

Το continuous collision envelope προσεγγίζει το συρμάτινο πλέγμα χωρίς να
προσομοιώνει κάθε σύρμα ως ξεχωριστή επαφή. Το generated SDF χρησιμοποιεί:

- effective floor friction `BASKET_FLOOR_MU=1.0`, ώστε να αναπαράγεται η
  αντίσταση κύλισης πάνω στις διασταυρώσεις του πλέγματος,
- compliant wall contact (`BASKET_LINING_CONTACT_KP/KD=4000/120`) και χαμηλό
  effective restitution `0.05`, ώστε ο ελαστικός mesh σκελετός να μη
  συμπεριφέρεται σαν άκαμπτη μεταλλική πλάκα.

Οι τιμές είναι environment-parameterized στο `generate_robot_urdf.py` για
controlled sweeps. Δεν σημαίνουν συμπαγές ή λαστιχένιο κουτί και δεν αλλάζουν
τη συμφωνημένη κατασκευή από συρμάτινο πλέγμα.

### 8.2 Diagnostic observability των spring carriages

Το `INTAKE_EXPOSE_CARRIAGE_STATE=true` προσθέτει τα δύο passive carriage
joints ως state-only interfaces στο Gazebo `ros2_control`, ώστε το physics
probe να καταγράφει θέση και ταχύτητα. Είναι αποκλειστικά diagnostic mode:
το A/B του debug log #50 έδειξε διαφορετική repeatability (`OFF 5/5`, `ON
4/5`). Για release evidence και load tests παραμένει πάντα `false` (default),
ώστε το instrumentation να μην αποτελεί μέρος της ελεγχόμενης φυσικής.

### 8.3 Controlled-launch handoff

Το opt-in `INTAKE_RAMP_PROFILE=launch` αντικαθιστά στο generated Gazebo SDF
τη μακριά rolling ramp με χαμηλό cubic kicker και μικρό air gap πριν από το
bin. Οι αρχικές παράμετροι δοκιμής είναι exit `x=0.465`, `z=0.032` και
`35deg`. Το stationary bench πέρασε 3/3, αλλά το moving collect_one 0/3 στο
τελικό retention gate: η μπάλα μπήκε και settled, έπειτα κύλησε προς τις
μπροστινές γωνίες κατά την κίνηση του robot.

Η αιτία ήταν τα δύο ακάλυπτα front-corner ανοίγματα ανάμεσα στο 180mm intake
channel και το 280mm bin, όχι υπερβολική ενέργεια εκτόξευσης. Προστέθηκαν δύο
mesh-equivalent corner retainers 50x20mm, αφήνοντας το κεντρικό launch opening
ελεύθερο. Το corrected collect_one smoke πέρασε 3/3 με τελική παραμονή μέσα
στο bin και το επίσημο corrected gate πέρασε 5/5. Το load-15 test που
ακολούθησε έδειξε κεντρικό rollback, οπότε εφαρμόστηκε το fixed lip του §8.4
αντί full-width compliant flap. Τα επόμενα load tests παραμένουν κλειστά μέχρι
ο launcher να περάσει το ballistic release contract.

### 8.4 Loaded centre-retention lip

Το έγκυρο load-15 test απέδειξε κεντρικό rollback: αποθηκευμένη μπάλα κύλησε
στο 180mm opening πριν φτάσει η νέα target και μπλόκαρε το handoff. Για αυτό
προστέθηκε αρχικά fixed centre lip `10x180x20mm`, παραμετρικό με
`BASKET_CENTER_LIP_HEIGHT_M`. Το unloaded run διατήρησε
transport 6/6 και basket 8/8, ενώ όλα τα επόμενα loaded runs κράτησαν 15/15
stored balls. Το retention interface θεωρείται επομένως λειτουργικό.

Η low-transition αναθεώρηση μείωσε το fixed lip σε `10mm` και πρόσθεσε την
κεκλιμένη υποδοχή, χωρίς να μειώσει το κύριο πάτωμα ή το ground clearance. Στο
load-25 run κράτησε 25/25 stored balls και τη νέα target μέσα (`basket 8/8`,
wheel transport 4/4). Η κίνηση έμεινε `vx=0.120m/s`, οι τέσσερις τροχοί
`1.4118rad/s`, roll/pitch `0deg`.

Το πρώτο load-45 gate απέτυχε στη διαχείριση των ανώτερων στρώσεων: κράτησε
42/45 stored balls, ενώ οι `stored_ball_29`, `stored_ball_39` και
`stored_ball_44` βγήκαν προς το intake και εμπόδισαν την target πριν από
έγκυρη επαφή με τους τροχούς. Η κίνηση παρέμεινε αμετάβλητη (`vx=0.120m/s`,
τέσσερις τροχοί `1.4118rad/s`, roll/pitch `0deg`).

**Κλείσιμο (log #54-#56)**: το load-45 gate έκλεισε με το entry hood
(§2) + rear clearance 0.120 + launch profile: loaded 5x **5/5 PASS 8/8**
(45/45 retained παντού), unloaded regression **5/5**, και clean-env
verification run 8/8 με τα νέα repo defaults. Το wheel-only rolling entry
απορρίφθηκε για loaded λειτουργία (2/5). Η γεωμετρία αυτού του spec μαζί
με το hood είναι πλέον το default σε generator/xacro/harness/compose.

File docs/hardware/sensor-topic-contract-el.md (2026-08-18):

# Sensor Topic Contract

Ενιαίο contract για τα sensors, κοινό σε sim και πραγματικό ρομπότ. Όλα τα layers
πάνω από τα drivers (perception, controller, planning) κάνουν subscribe **μόνο**
σε αυτά τα ονόματα — δεν ξέρουν αν από κάτω τρέχει Gazebo ή hardware.

## Contract

| ROS topic | Type | frame_id | Sim source | Real source |
| --- | --- | --- | --- | --- |
| `/scan` | `sensor_msgs/LaserScan` | `lidar_link` | gz `/gz/lidar` → ros_gz_bridge | rplidar driver |
| `/camera/image_raw` | `sensor_msgs/Image` (rgb8) | `camera_link` | gz `/gz/camera` → bridge | DepthAI/OAK-D driver |
| `/camera/depth` | `sensor_msgs/Image` (32FC1) | `camera_link` | gz `/gz/depth` → bridge | DepthAI/OAK-D driver |
| `/perception/ball_detections` | `tennis_robot_msgs/BallDetectionArray` | `camera_link_optical_frame` | simulated OAK-D neural pipeline | OAK-D DepthAI adapter |
| `/survey/vision` | `std_msgs/String` (JSON heartbeat) | camera acquisition | neural `net/fence` + matched depth | ίδιο neural model / OAK-D RGBD |
| `/odom` | `nav_msgs/Odometry` | `odom`→`base_link` | `diff_drive_controller` | `diff_drive_controller` |
| `/ir/readings` | `tennis_robot_msgs/IrReadings` | `base_link` | `gazebo_extras_node` (από `/gz/ir_*`) | IR GPIO node |

Σημ.: το `/odom` πλέον δεν έρχεται από το Gazebo αλλά native από το
`diff_drive_controller`, ίδιο σε sim και real.

## Γιατί κρατάει την αρχιτεκτονική ενιαία

Η μόνη διαφορά sim↔real είναι **ποιος δημοσιεύει** σε αυτά τα topics:

```text
SIM:   Gazebo sensor plugin → ros_gz_bridge → /scan, /camera/*
REAL:  rplidar / DepthAI driver →             /scan, /camera/*   (ίδια ονόματα)
```

Για να παραμείνει σταθερό, ο πραγματικός driver πρέπει να ευθυγραμμιστεί σε:

1. **Topic name** — μέσω remapping στο `real_sensors.launch.py`.
2. **frame_id** — ο driver να δηλώνει `lidar_link` / `camera_link` (ίδια με το URDF),
   αλλιώς το TF δεν κλείνει.
3. **Message type/encoding** — `LaserScan`, `Image rgb8`, depth `Image 32FC1` σε **μέτρα**
   (το OAK-D βγάζει συχνά `16UC1` σε mm — χρειάζεται μετατροπή σε `32FC1` m).
4. **`use_sim_time`** — `true` στο sim, `false`/unset στο real.

Το perception node επεξεργάζεται **ένα timestamp-matched RGB/depth pair** και
τρέχει δύο υποχρεωτικά ONNX models: το tiny-ball detector και το court-scene
`net/fence` detector. Το `/survey/vision` δημοσιεύει `obstacle_source =
neural_court_scene`, confidence, bbox, bearing και depth. Δεν υπάρχει classical
net/fence runtime fallback· απουσία ή invalid model αποτυγχάνει στο startup.

## Frame tree (κοινό)

```text
odom → base_link → lidar_link
                 → camera_link
                 → left_wheel_link / right_wheel_link / lift_wheel_link
```

`base_link → *` από `robot_state_publisher` (URDF).
`odom → base_link` από `diff_drive_controller`.

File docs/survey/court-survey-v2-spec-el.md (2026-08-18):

# Court Survey v2 — LiDAR Occupancy → Court Knowledge Model (as-built)

> Η **έγκυρη, τελική** προδιαγραφή του survey. Αντικατέστησε το dead-reckoning
> perimeter FSM (εύθραυστο) και είναι πλέον **υλοποιημένη και επικυρωμένη στο
> Gazebo**: Map Court → πλήρες `court_boundary.json` με σωστές αποστάσεις, καθαρό
> χάρτη και 0 ψεύτικα obstacles σε άδειο γήπεδο. Όλα τα προηγούμενα survey
> documents (perimeter / Nav2-explore / FSM-fix) είναι ξεπερασμένα.

## 1. Σκοπός & αρχές

**Σκοπός:** Στο τέλος της χαρτογράφησης το robot γνωρίζει:

1. Πού είναι οι **φράχτες** (εξωτερικό όριο).
2. Πόσο **απέχουν οι φράχτες από τις γραμμές** (run-off ανά πλευρά).
3. Πού είναι το **δίχτυ** και οι **δύο στύλοι** του.
4. Κάθε **άλλο εμπόδιο εντός των φραχτών** (πάγκοι, στύλοι) — θέση + μέγεθος.

Η κίνηση είναι το **μέσο**, όχι ο σκοπός: το ζητούμενο είναι η ΜΕΤΡΗΣΗ.

**Αρχές σχεδίασης (μη διαπραγματεύσιμες):**

- **LiDAR-first.** Ό,τι είναι κάθετο (φράχτες, δίχτυ, στύλοι, εμπόδια) και κάθε
  απόσταση **μετριέται από το 360° LiDAR**. Η κάμερα OAK-D χρησιμοποιείται στη Φάση 1
  **μόνο για τη neural επιβεβαίωση του φιλέ** (custom ONNX `net/fence`
  classification που σκανδαλίζει το net lock μέσω `/survey/vision`)· η
  θέση/απόσταση του φιλέ έρχεται από το LiDAR. Η semantic detection και το depth
  προέρχονται από το ίδιο timestamp-matched RGB/depth pair, επιβεβαιώνονται σε
  διαδοχικά frames και λήγουν όταν σταματήσει το heartbeat. Καμία γεωμετρία δεν
  προκύπτει από την κάμερα και δεν υπάρχει OpenCV semantic fallback.
- **Μέτρηση από τον χάρτη, όχι από στιγμιαία pose.** Οι αποστάσεις είναι διαφορές
  παγκόσμιων θέσεων στον συσσωρευμένο occupancy χάρτη.
- **Standard διαστάσεις για τις γραμμές.** Οι γραμμές (αόρατες στο LiDAR) προκύπτουν
  από το δίχτυ ως άγκυρα + κανονιστικές διαστάσεις ITF.
- **Ίδιος κώδικας σε Gazebo & πραγματικό ρομπότ.** Διαφορές μόνο μέσω env vars/topics.
- **ΚΑΘΑΡΗ ΥΛΟΠΟΙΗΣΗ — ΧΩΡΙΣ FALLBACKS.** Καμία σιωπηλή εκτίμηση/default. Αν ένα βήμα
  δεν έχει αρκετά δεδομένα ή αποτυγχάνει δομικός έλεγχος, το survey **αποτυγχάνει
  ρητά** (fail-loud) με σαφή αιτία και ΔΕΝ γράφει επινοημένο boundary. Η μόνη
  «σταθερά» που επιτρέπεται είναι οι **κανονιστικές διαστάσεις γηπέδου**.

## 2. Κανονιστικές διαστάσεις (ITF) — η μόνη επιτρεπτή σταθερά

| Στοιχείο | Τιμή |
| --- | --- |
| Μήκος γηπέδου (baseline→baseline) | 23.77 m (half = 11.885 m) |
| Πλάτος doubles | 10.97 m (sideline ±5.485 m) |
| Πλάτος singles | 8.23 m |
| Service line από δίχτυ | 6.40 m |
| Net post span (doubles) | 11.3 m (στύλοι ±5.65 m) |

Tunable μέσω `CourtSpec` / env, με κανονιστικά defaults.

## 3. Αρχιτεκτονική / data flow

```
/scan (360° LiDAR) ─┐
                    ├─► [1] Occupancy accumulation (map frame, voxel grid)
TF map→<scan frame>─┘            │  → court_survey_live.json (live points)
                                ▼
                       [2] Coverage controller (deterministic drive)
                       8 vantage points στο court frame + return pass
                                │  (μέτρηση κλειδώνει νωρίς, η οδήγηση
                                ▼   συνεχίζει για πλήρη/loop-closed χάρτη)
                       [3] Extraction (pure functions, offline-testable)
                         3a Net+posts → court frame   3d Obstacles (+smart filter)
                         3b Fence rectangle           3e Distances (run-off)
                         3c Court lines (standard)     3g Fail-loud checks
                                │
                                ▼
                       [4] court_boundary.json (Court Knowledge Model v2)
```

Τα βήματα **[3a–3g] είναι καθαρές συναρτήσεις** (`court_extraction.py`) → unit-testable
χωρίς ROS, με synthetic point clouds.

## 4. Coverage controller (`court_survey_v2_node.py` + `court_coverage.py`)

States: `INIT → FIND_NET → COVERAGE → DONE/FAILED`.

- **FIND_NET:** οδήγηση μπροστά μέχρι το δίχτυ· το **net lock** σκανδαλίζεται από την
  επιβεβαιωμένη OAK-D neural net classification (`obstacle_source =
  neural_court_scene`, confidence gate, heartbeat age ≤ 1 s) και παίρνει την
  απόσταση/θέση του φιλέ από το μπροστινό LiDAR range → ορίζει το court frame
  (origin = net center, +x' = robot→net, +y' = κατά μήκος του διχτιού).
- **Deterministic drive-to-waypoint** (closed-loop στο SLAM pose) — **όχι Nav2**, που
  αποδείχθηκε ασταθές run-to-run. 8 waypoints στο court frame:
  1. `(-deep, 0)` βαθιά κοντινό μισό → πυκνός κοντινός φράχτης
  2. `(-2, +gap)` έξω στο gap (κοντινή πλευρά)
  3. `(+2, +gap)` πέρασμα x'=0 από το gap (καθαρά από το δίχτυ)
  4. `(+quarter, 0)` κέντρο μακρινού μισού
  5. `(+deep, 0)` βαθιά μακρινό μισό → πυκνός μακρινός φράχτης
  6–8. **Return pass:** `(+2, -gap) → (-2, -gap) → (-quarter, 0)` ξαναπερνά το δίχτυ
     από το άλλο gap και επιστρέφει στο κοντινό μισό.
  όπου `deep = half_length + 4`, `gap = post_half_span_doubles + 1.05 ≈ 6.7 m`.
- **Fence-approach stop:** όταν το μπροστινό LiDAR δει φράχτη < ~1.4 m ενώ κοιτάζει το
  waypoint, σταματάει. Λαμβάνει υπόψη το **footprint** (το σώμα φτάνει ~0.54 m
  μπροστά από το LiDAR) → πυκνή χαρτογράφηση φράχτη χωρίς τρακάρισμα.
- **Decouple μέτρησης / χάρτη:** η μέτρηση **κλειδώνει στην πρώτη επιτυχή εξαγωγή**
  (ξέρουμε ότι δεν είναι αποτυχία), αλλά το ρομπότ **συνεχίζει** όλη τη διαδρομή και
  ξανα-εξάγει στον πληρέστερο/loop-closed χάρτη· `DONE` μόνο στο τέλος. Fail-loud
  μόνο αν δομική αποτυχία **πριν** κλειδώσει η μέτρηση.

> Η κίνηση δεν χρειάζεται ακρίβεια — μόνο να φέρει τις πλευρές εντός εμβέλειας. Η
> μέτρηση γίνεται από τον χάρτη.

## 5. Extraction — αλγόριθμοι (`court_extraction.py`)

### 3a. Δίχτυ + στύλοι → court frame
- Από `locked_net`: net center `C` (map frame) και κατεύθυνση robot→net = **άξονας
  μήκους** `û`· άξονας πλάτους `v̂ = perp(û)`. Court frame: origin `C`, άξονες `(û, v̂)`.
- **Στύλοι:** το φυσικό γήπεδο είναι **doubles-width**· οι στύλοι (±5.65 m) προκύπτουν
  από **standard geometry** αγκυρωμένη στο μετρημένο net center (όχι από εύθραυστο
  post-span fit). Το singles είναι εσωτερικό subset βαμμένων γραμμών (μελλοντική
  κάμερα).

### 3b. Fence rectangle
- Μετασχηματισμός όλων των map_points σε court frame.
- Προβολή σε `x'`/`y'` → histogram (bins 0.15 m) → οι **δύο ακραίες πυκνές κορυφές** =
  near/far φράχτες (`x_near, x_far`) και side φράχτες (`y_left, y_right`).
- **Coverage gate:** απαιτείται έκταση `≥ half_length + 2` ώστε ο **φράχτης** (πέρα από
  τη baseline) — όχι μόνο η baseline — να είναι μέσα στο πεδίο πριν το fit. Κάθε
  πλευρά απαιτεί `≥ fence_side_min_points`.

### 3c. Court lines (net-anchor, standard — χωρίς κάμερα)
Στο court frame: baselines `x'=±11.885`, service `x'=±6.40`, center line `y'=0`,
sidelines `y'=±5.485` (doubles).

### 3d. Obstacles εντός φραχτών (+ smart fence-artifact filter)
- Υποψήφια = σημεία εντός fence rectangle (margin **0.9 m**) που δεν ανήκουν στη ζώνη
  διχτιού (band **0.8 m** γύρω από x'=0).
- **Clustering** (grid connected cells) → bounding box (θέση + μέγεθος).
- **Smart fence-artifact rejection:** cluster **κοντά** σε φράχτη (< 1.8 m) **και**
  επιμηκυμένο **παράλληλα** σε αυτόν = scatter του φράχτη → απορρίπτεται. Πραγματικό
  εμπόδιο που **προεξέχει προς τα μέσα** (επιμηκυμένο κάθετα) ή είναι μακριά από
  φράχτη → κρατιέται. Αποτέλεσμα: **0 ψεύτικα obstacles** σε άδειο γήπεδο.

### 3e. Distances (run-off) — διαφορές θέσεων στον χάρτη
`near = |x_near| − 11.885`, `far = x_far − 11.885`,
`left = |y_left| − 5.485`, `right = y_right − 5.485`.

### 3f. Singles/doubles
**Bypassed:** `is_doubles = True` πάντα (φυσικό γήπεδο doubles-width). Το run-off
εξακολουθεί να **μετριέται** από τους φράχτες — αυτό είναι που διαφέρει ανά γήπεδο.

### 3g. Fail-loud vs recoverable (η «καρδιά» του no-fallbacks)
Κρίσιμη διάκριση που έλυσε το βασικό bug ολοκλήρωσης:

| Κατάσταση | Ταξινόμηση | Αιτία |
| --- | --- | --- |
| Δίχτυ χωρίς αρκετά σημεία | structural fail-loud | `net_not_observed` |
| Λείπει πλευρά φράχτη / λίγη κάλυψη | **recoverable** → συνέχισε coverage | `coverage_incomplete`, `fence_side_missing` |
| **Αρνητικό** run-off (fit κόλλησε στο δίχτυ πριν χαρτογραφηθεί ο μακρινός φράχτης) | **recoverable** (ΟΧΙ structural) | `coverage_incomplete: <side> fence not yet mapped` |
| **Θετικό** run-off > 12 m | structural fail-loud | `nonstandard_or_bad_fit` |
| Όλα τα vantage points εξαντλήθηκαν χωρίς μέτρηση | structural fail-loud | `coverage_incomplete: all vantage points visited` |

> Ένας φράχτης δεν μπορεί να βρίσκεται **μέσα** στη baseline· αρνητικό run-off σημαίνει
> «δεν χαρτογραφήθηκε ακόμα ο πραγματικός φράχτης» = πρόβλημα κάλυψης, όχι μη-στάνταρ
> γήπεδο. Αυτή η ταξινόμηση εμποδίζει το survey να αυτοκτονήσει πριν φτάσει στον
> μακρινό φράχτη.

## 6. Σχήμα εξόδου — `court_boundary.json` (Court Knowledge Model v2)

```json
{
  "schema": "court_knowledge_model/v2",
  "status": "OK",
  "failure_reason": null,
  "frame": "map",
  "net": {
    "center": {"x_m": 8.04, "y_m": 0.0},
    "axis_length": {"x_m": 1.0, "y_m": 0.0},
    "axis_width":  {"x_m": 0.0, "y_m": 1.0},
    "posts": [{"x_m": 8.04, "y_m": 5.65}, {"x_m": 8.04, "y_m": -5.65}],
    "span_m": 11.3
  },
  "court": {
    "is_doubles": true, "length_m": 23.77, "width_m": 10.97,
    "lines_court_frame": {
      "baselines_x": [-11.885, 11.885], "service_x": [-6.4, 6.4],
      "sidelines_y": [-5.485, 5.485], "center_line_y": 0.0
    }
  },
  "fence": {
    "corners": [{"x_m": -8.59, "y_m": -8.46}, "...x4"],
    "extents_court_frame": {"x_near": -16.63, "x_far": 16.37, "y_left": -8.46, "y_right": 8.79}
  },
  "distances_to_fence_m": {
    "near_baseline": 4.75, "far_baseline": 4.48,
    "left_sideline": 3.28, "right_sideline": 3.31
  },
  "obstacles": [
    {"id": 1, "class": "obstacle", "center": {"x_m": 5.0, "y_m": 1.0},
     "size_m": {"w": 0.4, "h": 1.2}, "point_count": 42}
  ],
  "map_artifact": {
    "status": "saved",
    "basename": "runtime/maps/court_1781845000",
    "files": {"posegraph": "...", "data": "...", "yaml": "...", "pgm": "..."},
    "court_frame": {"center": {"x_m": 8.04, "y_m": 0.0},
                    "axis_length": {"x_m": 1.0, "y_m": 0.0},
                    "axis_width": {"x_m": 0.0, "y_m": 1.0}}
  },
  "occupancy": {"point_count": 1500},
  "surveyed_at": 0
}
```

## 7. SLAM & μοντέλο — διορθώσεις που έκαναν τον χάρτη καθαρό/πλήρη

- **Loop closure (slam_toolbox) ενεργό αλλά συντηρητικό:** search μόνο < 3 m (ποτέ δεν
  ταιριάζει τον απέναντι φράχτη), αυστηρά response thresholds, + το δίχτυ/γωνίες
  σπάνε την κατά-μήκος ασάφεια. Χωρίς αυτό, το odometry drift μεταξύ των δύο μισών
  «δίπλωνε» το δίχτυ σε διπλή γραμμή. Δουλεύει μαζί με το **return pass** (§4) που
  δίνει την επικάλυψη για να κλείσει ο βρόχος.
- **Net visual strand στο ύψος του LiDAR:** το `gpu_lidar` βλέπει **visuals** (όχι το
  collision box)· το πλέγμα κλωστών άφηνε κενό στα 0.713 m. Προστέθηκε συνεχής
  οριζόντια λωρίδα στο `model.sdf` → σταθερό net lock ανά scan.

## 7.1 SLAM map serialization για Nav2 (collection phase)

Όταν το survey ολοκληρώνεται (state `SAVING_MAP` πριν το `DONE`), ο node **σειριοποιεί
best-effort** τον slam_toolbox χάρτη ώστε να τον ξαναφορτώνει το Nav2 χωρίς νέο mapping:

- `serialize_map` → `runtime/maps/court_<ts>.posegraph` + `.data` (για slam_toolbox
  **localization mode** — ταιριάζει με το SLAM-based `navigation.launch.py`).
- `save_map` → `.pgm` + `.yaml` (occupancy grid, για επιθεώρηση / map_server+AMCL).
- Τα paths + το **court frame** (center + άξονες) γράφονται στο `court_boundary.json`
  ως `map_artifact`. Έτσι μετρήσεις (Knowledge Model) και grid μοιράζονται **ένα
  κοινό frame**.

Best-effort & **fail-safe**: αν τα services λείπουν ή λήξει το timeout, το survey
ολοκληρώνεται κανονικά με την (έγκυρη) μέτρηση — απλώς `map_artifact.status` =
`error`/`pending`. Δεν μπλοκάρει ποτέ.

Η βάση κρατά το `map_artifact` μέσα στο raw_json κάθε survey· το
`TennisRobotDB.current_survey(court_id)` το εκθέτει στη φάση συλλογής για να φορτωθεί
ο σωστός χάρτης ανά court. (Επόμενο βήμα (4): inject των CKM obstacles ως Nav2
keepout/obstacle layer.)

## 8. Panel — Sensor Views (`survey_map_v2.js`)

Αυτόνομο module που, όταν `schema === "court_knowledge_model/v2"`, ζωγραφίζει
κατευθείαν από το v2: live LiDAR points, περίγραμμα φράχτη (`fence.corners`), δίχτυ +
posts, εσωτερικές γραμμές μέσω του net frame, run-off βελάκια + πίνακας αποστάσεων,
obstacles, θέση ρομπότ, status (OK/FAILED/live-error, fail-loud). Το `app.js` κάνει
delegate στο call site· η παλιά v1 λογική μένει ως fallback.

## 9. Χάρτης αρχείων (as-built)

| Αρχείο | Ρόλος |
| --- | --- |
| `tennis_robot/court_extraction.py` | Pure μετρητική (3a–3g), offline-testable |
| `tennis_robot/court_coverage.py` | Vantage points (8 + return pass), recoverable classifier |
| `tennis_robot/court_survey_v2_node.py` | Coverage controller (FIND_NET→COVERAGE→DONE), decouple |
| `tennis_robot/court_survey_mission_node.py` | Delegation stub → v2 node |
| `config/slam_toolbox.yaml` | SLAM + conservative loop closure |
| `gazebo/models/tennis_court/model.sdf` | net strand στο ύψος LiDAR |
| `runtime/maps/court_<ts>.*` | Σειριοποιημένος SLAM χάρτης per survey (Nav2) |
| `scripts/control_panel/survey_map_v2.js` | Panel v2 renderer |
| `tests/test_court_extraction.py`, `tests/test_court_coverage.py` | Offline tests |

## 10. Επικύρωση

End-to-end στο Gazebo: Map Court → `survey OK (map complete)`, αποστάσεις φράχτη
συμμετρικές (~4.7 / 4.5 / 3.3 / 3.3 m), **0 obstacles** σε άδειο γήπεδο, δίχτυ ως μονή
γραμμή μετά το loop closure. Offline: όλα τα `test_court_*` περνούν (synthetic courts,
rotated/translated invariance, missing-side & nonstandard fail-loud, artifact filter).

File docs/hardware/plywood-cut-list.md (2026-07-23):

# Plywood Cut List For First Chassis

> **Historical / superseded:** this cut list describes the removed 760 x 430 mm
> first-chassis CAD. The active Gazebo robot is 920 x 580 mm and uses the
> dual-wheel intake plus basket v2.1. Do not manufacture from this document;
> use it only as project history until a new SCAD and cut list are produced.

Material:

```text
Birch marine plywood sheet: 1000 x 700 x 21 mm
```

The removed CAD reference remains available in Git history at commit `de75682`.

For the full physical-store shopping checklist, including motors, wheels,
collector parts, fasteners, and safety electronics, see:

```text
docs/hardware/prototype-purchase-list-el.md
```

Ask the shop to keep the cuts square and to account for saw kerf, usually
about 3-5 mm per cut. Dimensions below are finished part dimensions.

## Base Top View

Base layout plan

Historical CAD reference: commit `de75682`, path
`cad/3d-printable-base/base_mounting_plate.scad`.

## Required Cuts
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

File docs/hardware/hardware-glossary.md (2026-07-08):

# Hardware Glossary

## VM (Motor Voltage)

Τροφοδοσία ισχύος του driver.

* Συνήθως 6–15V (ανάλογα με τον driver)
* Πηγαίνει στα μοτέρ
* Στον collector: **12V**

---

## VCC (Logic Voltage)

Τροφοδοσία λογικής του chip.

* Συνήθως 5V ή 3.3V
* Δεν τροφοδοτεί το μοτέρ
* Τροφοδοτεί τα εσωτερικά κυκλώματα του driver

Στον TB6612:

**VCC = 5V**

---

## GND (Ground)

Κοινή αναφορά τάσης.

Όλες οι συσκευές πρέπει να μοιράζονται το ίδιο GND.

```text
Arduino GND
TB6612 GND
12V PSU -
Buck GND
IR GND
```

Όλα συνδέονται μαζί.

---
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

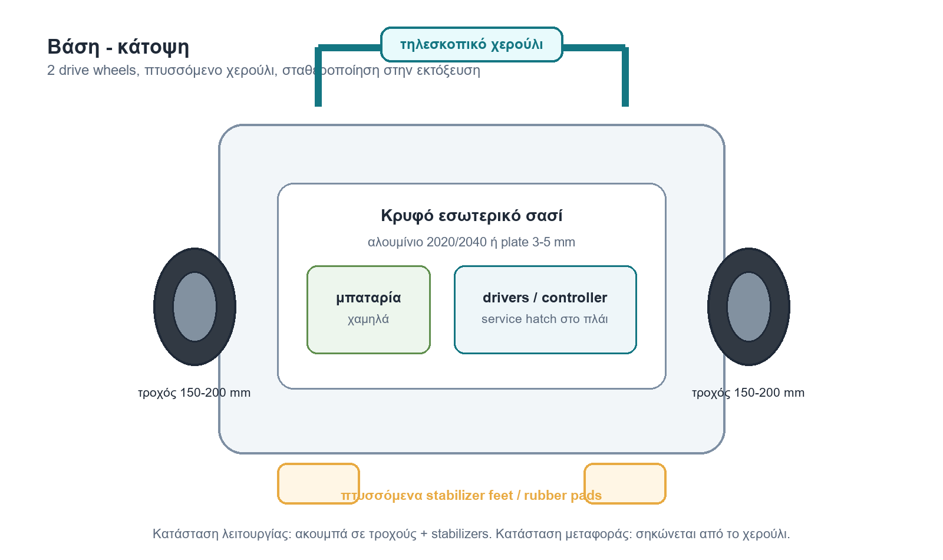
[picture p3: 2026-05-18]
docs/images/design-base-plan.png

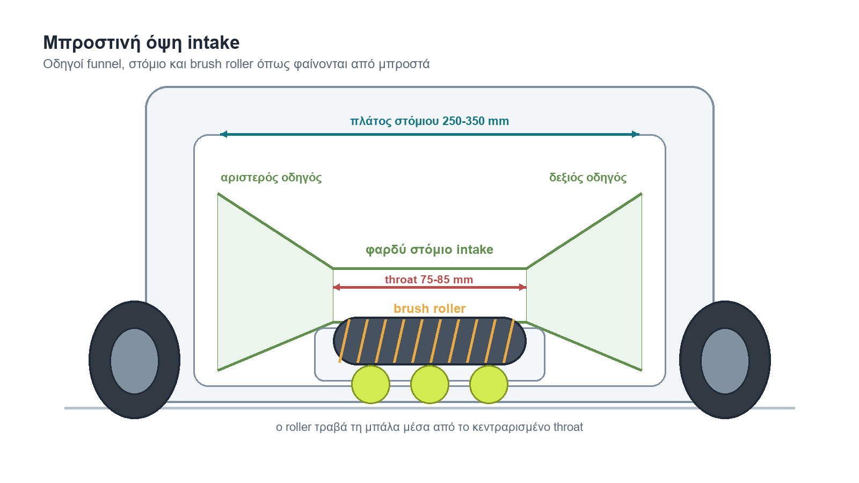
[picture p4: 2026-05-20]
docs/images/design-intake-front-view.png

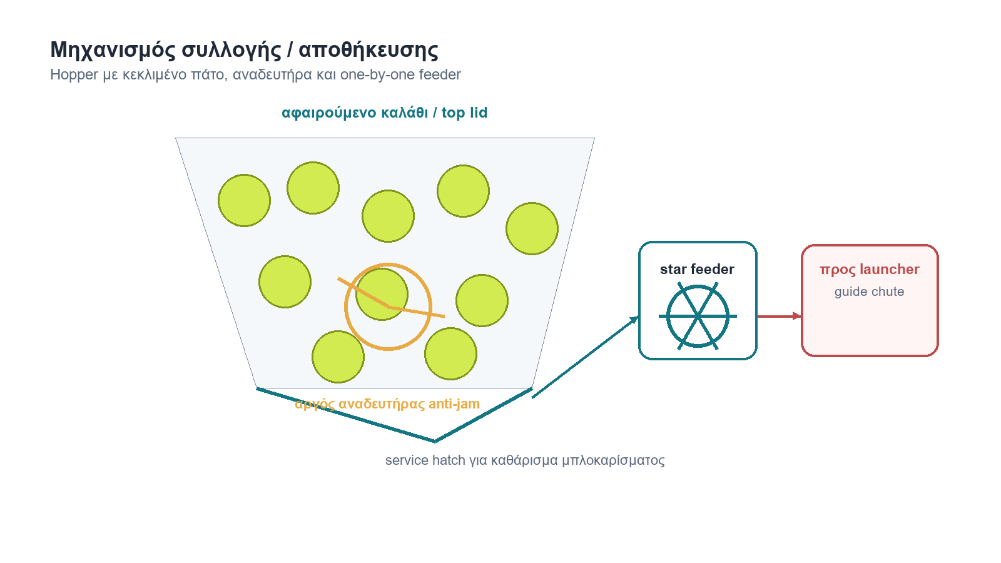
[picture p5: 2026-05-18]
docs/images/design-collection-hopper.png

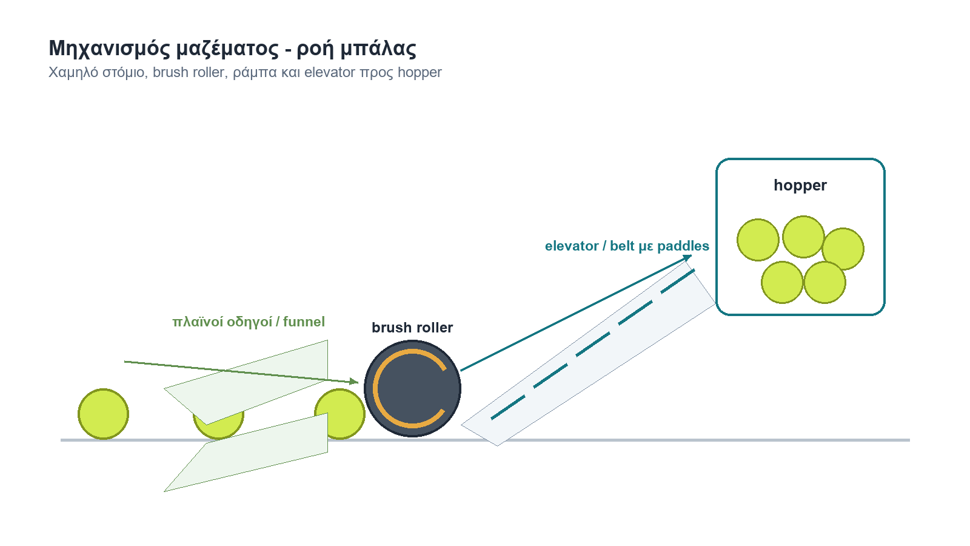
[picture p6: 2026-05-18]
docs/images/design-pickup-flow.png

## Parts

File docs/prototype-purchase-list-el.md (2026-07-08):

# Λίστα Παραγγελίας Πρώτου Prototype

Σκοπός: αγορά υλικών για το πρώτο φυσικό prototype του tennis robot:

```text
ξύλινη βάση + κινητήρια βάση + front collector + βασική ασφάλεια
```

## Sensor Baseline Update

Η νέα baseline επιλογή αισθητήρων είναι:

```text
Waveshare/Slamtec RPLIDAR C1 low 360 LiDAR -> obstacle scan / shadow zones / wall-net-fence clearance / route costmap
OAK-D S2 top camera -> ball detection / hidden ball recovery / ball distance / ball map
Encoders + IMU -> odometry / robot pose
```

Το Waveshare/Slamtec RPLIDAR C1 μπαίνει χαμηλά στο robot για real-time χάρτη εμποδίων, όρια γηπέδου, shadow zones και costmap. Δεν το χρησιμοποιούμε ως αξιόπιστο ball detector, γιατί η μπάλα 6.7 cm δίνει αδύναμο/ασταθές 2D return. Η OAK-D S2 μένει ψηλά ως ο κύριος αισθητήρας για ball detection, depth και targeted look σε περιοχές που το LiDAR δείχνει κρυμμένες ή μπλοκαρισμένες.

Προσθήκη στη λίστα αγοράς electronics/sensors:

| Qty | Είδος | Χρήση |
|---:|---|---|
| 1 | Waveshare/Slamtec RPLIDAR C1 από Amazon.de | Χαμηλό 360° 2D LiDAR για costmap, εμπόδια, shadow zones, φιλέ/τοίχο/φράχτη και ROS 2 navigation |
| 1 | USB/serial cable ή adapter που απαιτεί το C1 kit | Σύνδεση στο SBC / mini PC |
| 1 set | M3/M4 guarded, vibration-isolated lower mounting bracket | Σταθερή χαμηλή οριζόντια τοποθέτηση LiDAR, προστατευμένη από χτυπήματα και χωρίς να κόβεται το 360° scan από ρόδες/funnel |

Πάρε αυτή τη λίστα σε φυσικό κατάστημα ξυλείας/σιδηρικών/ηλεκτρονικών. Οι
διαστάσεις είναι σε mm όπου δεν αναφέρεται κάτι άλλο.

## 1. Ξύλινη Βάση

Υλικό επιλογής:

```text
Κόντρα πλακέ θαλάσσης σημύδα 12-15 mm, φύλλο περίπου 70 x 100 cm
```

Προτίμηση:

```text
15 mm αν υπάρχει.
12 mm αν θέλουμε πιο ελαφριά βάση.
21 mm μόνο αν θέλουμε πολύ στιβαρό αλλά βαρύ prototype.
```

Κοπή:

| Qty | Διαστάσεις | Περιγραφή |
|---:|---|---|
| 1 | 760 x 430 | Κύρια κάτω βάση |
| 2 | 760 x 45 | Μακριά πλαϊνά rails/νευρώσεις |
| 3 | 390 x 45 | Εγκάρσιες νευρώσεις |
| 2 | 180 x 90 | Collector upright plates |
| 2 | 220 x 80 | Hopper/back-plate supports |
| 4 | 120 x 80 | Motor pod reinforcement plates (4WD: one per pod) |
| 2 | 130 x 60 | Stabilizer bracket blocks |
| 2 | 100 x 60 | Handle socket backing plates |

Να υπολογιστεί απώλεια κοπής 3-5 mm ανά πέρασμα δίσκου.

## 2. Κίνηση Βάσης

### Drive Motors

Ζητάμε:

```text
4 τεμάχια DC gear motor 12V με encoder
```

Ιδανικά χαρακτηριστικά:

| Χαρακτηριστικό | Στόχος |
|---|---|
| Τάση | 12 V DC |
| Ταχύτητα | περίπου 120 RPM με τροχό 180 mm |
| Encoder | Ναι, quadrature αν γίνεται |
| Άξονας | 6 mm ή 8 mm D-shaft |
| Rated torque | τουλάχιστον 15-18 kg.cm |
| Stall current | να αναγράφεται στο datasheet |
| Gearbox | μεταλλικό |

Προτεινόμενο συγκεκριμένο μοντέλο για το prototype:

```text
4 τεμάχια Metal DC Geared Motor w/Encoder - 12V 122RPM 38Kg.cm
Link: https://grobotronics.com/metal-dc-geared-motor-w-encoder-12v-122rpm-38kg.cm.html
```

Χαρακτηριστικά του συγκεκριμένου μοτέρ:

| Χαρακτηριστικό | Τιμή |
|---|---|
| Motor type | Brushed DC gear motor με integrated quadrature encoder |
| Rated voltage | 12 V DC |
| No-load speed | 122 RPM |
| Rated torque | 38 kg.cm |
| Encoder | Ναι |
| Wheel target | 170 mm driven wheels (HPI Dirt Buster Block, αγοράστηκαν) |

Αυτό το setup αλλάζει τη βάση σε 4WD differential/skid-steer, χωρίς μπροστινούς
casters. Με τροχό 180 mm και 122 RPM η θεωρητική ταχύτητα είναι περίπου
1.15 m/s χωρίς φορτίο. Το χαμηλότερο RPM και η μεγαλύτερη ροπή είναι πιο
κατάλληλα για σταθερό πρώτο prototype, ειδικά με 4WD skid-steer σε γήπεδο.

Αν δεν υπάρχει με encoder:

```text
Δεν το προτιμάμε για τη βάση. Για αυτόνομη κίνηση και odometry θέλουμε encoder
σε κάθε drive motor ή τουλάχιστον αξιόπιστο encoder ανά πλευρά.
```

Specs επιβεβαιωμένα (DFRobot FIT0403):

- Encoder: ναι, quadrature· gearbox 90:1.
- **Shaft: 6 mm D-shaft** (επιβεβαιωμένο από datasheet + μέτρηση).
- Rated/stall current: ~7 A stall @ 12 V.
- Hub: **απαιτείται adapter 6 mm D-shaft → 24 mm hex** (βλ. ordered-parts.md → Parts To Order).

### Driven Wheels

**ΑΓΟΡΑΣΤΗΚΑΝ:** 4 × HPI Racing Dirt Buster Block Tire S Compound on Black Wheel
(Baja 5B Rear, 170x80 mm, μονταρισμένα με foam inserts). 2 ζευγάρια, μεταχειρισμένα
από RC offroad (8 kg, 90+ χλμ/ώ τελική) — άφθονη αντοχή για συλλέκτη μπαλών.

| Χαρακτηριστικό | Πραγματικό |
|---|---|
| Διάμετρος | 170 mm (radius 0.085 → ενημερώθηκε στο URDF + controllers.yaml) |
| Πλάτος | 80 mm |
| Πάτημα | rubber, S (soft) compound — καλό grip σε clay |
| Hub | **24 mm hex** (πρότυπο Baja 5B) |
| Στήριξη | **24 mm hex adapter, 6 mm bore (D-shaft)** προς τον FIT0403 (βλ. ordered-parts.md → Parts To Order) |

> Επόμενο βήμα: παραγγελία 4× hub adapters **6 mm D-shaft → 24 mm hex**.

### Front Casters

Δεν ζητάμε πλέον front casters για την κύρια κινητήρια βάση:

```text
Νέα baseline: 4 driven wheels, χωρίς casters, για καλύτερη πρόσφυση και πιο
προβλέψιμο έλεγχο σε ταχύτητα/στροφή.
```

Σημείωση CAD redesign:

```text
Το CAD πρέπει να ενημερωθεί από 2WD + front casters σε 4WD skid-steer:
δύο αριστεροί και δύο δεξιοί κινητήριοι τροχοί, με αντίστοιχα motor pods και
χώρο για 4 drivers / καλωδίωση / ασφάλειες.
```

## 3. Motor Drivers Και Τροφοδοσία Κίνησης

Ζητάμε:

```text
2 τεμάχια motor driver για brushed DC motor στο πρώτο prototype
```

Budget επιλογή:

```text
BTS7960 / IBT-2 driver, ένας ανά πλευρά
Link: https://grobotronics.com/high-power-dc-motor-driver-dual-bts7960-half-bridge-43a.html
```

Στο πρώτο prototype κάθε BTS7960 οδηγεί τα δύο μοτέρ της ίδιας πλευράς
παράλληλα:

```text
Left BTS7960  -> left front motor + left rear motor
Right BTS7960 -> right front motor + right rear motor
```

Αν δούμε θερμοκρασίες, υπερβολικό ρεύμα, άνισο τράβηγμα ή κακή απόκριση στα
encoders, προσθέτουμε άλλα 2 BTS7960 ώστε να πάμε σε ένα driver ανά μοτέρ.

Prototype drive cost snapshot, 2026-06-21:

| Qty | Είδος | Link | Τιμή μονάδας | Σύνολο |
|---:|---|---|---:|---:|
| 4 | Metal DC Geared Motor w/Encoder - 12V 122RPM 38Kg.cm | https://grobotronics.com/metal-dc-geared-motor-w-encoder-12v-122rpm-38kg.cm.html | 36,00 € | 144,00 € |
| 2 | High-Power DC Motor Driver Dual BTS7960 Half-bridge 43A | https://grobotronics.com/high-power-dc-motor-driver-dual-bts7960-half-bridge-43a.html | 15,90 € | 31,80 € |
| 1 | Arduino Mega 2560 Rev3 | https://grobotronics.com/arduino-mega-2560-rev3.html | 39,00 € | 39,00 € |
|  | **Subtotal κίνησης χωρίς τροχούς/μεταφορικά** |  |  | **214,80 €** |

Το Arduino Mega μπαίνει ως ξεχωριστό motion MCU για encoders, PID ταχύτητας,
acceleration ramps και watchdog. Teensy/ESP32 παραμένουν καλύτερες/εναλλακτικές
επιλογές, αλλά το Mega είναι απλό και διαθέσιμο για πρώτο bring-up.

Να αγοραστεί αφού:

1. κουμπώσει η ξύλινη βάση,
2. τοποθετηθούν motor pods / τροχοί,
3. ξέρουμε το πραγματικό ρεύμα των drive motors,
4. επιβεβαιώσουμε ότι ο driver καλύπτει το stall/peak current των μοτέρ.

Για production-like έκδοση, αντικαθιστούμε τα BTS7960 με 2 ποιοτικούς
dual-channel DC motor drivers ή 4 ποιοτικούς single-channel drivers με
τεκμηριωμένο continuous current, προστασίες και ιδανικά current sensing.
Ο collector μπορεί να χρησιμοποιήσει μικρότερο H-bridge ή άλλο BTS7960 αν
θέλουμε κοινό hardware.

Χαρακτηριστικά:

| Χαρακτηριστικό | Στόχος |
|---|---|
| Motor voltage | 12 V ή 6-27 V range |
| Control | PWM + direction |
| Logic | 3.3 V / 5 V compatible |
| Current | αρκετό για stall current του μοτέρ |
| Cooling | heatsink, να αερίζεται |

Προσοχή: τα “43A” στα BTS7960 είναι συνήθως peak/marketing. Θέλουμε να ξέρουμε
το πραγματικό stall current των μοτέρ και να βάλουμε ασφάλεια.

## 4. Collector Module

### Funnel / Collector Body

Υλικά:

| Qty | Υλικό | Περιγραφή |
|---:|---|---|
| 1 set | PETG/ASA print ή πλαστικό φύλλο 2-3 mm | Funnel side plates και intake guides |
| 1 | πλαστικό/plywood plate | Adjustable back plate |
| 1 | διάφανο πλαστικό φύλλο 2-3 mm | Hopper/bin, για να βλέπουμε τις μπάλες |
| 1 set | μικρές γωνίες ή brackets | Για ρυθμιζόμενη σύνδεση funnel/back plate |

Διαστάσεις στόχοι:

| Χαρακτηριστικό | Στόχος |
|---|---|
| Funnel mouth width | 220-300 mm |
| Throat width | 75-85 mm |
| Bottom lip height | 5-12 mm από το έδαφος |
| Hopper capacity | 3-6 μπάλες |

### Wide Intake Roller / Cylinder

Ζητάμε:

```text
1 τεμάχιο wide compliant rubber/PU/TPU roller/cylinder, μήκος 240-300 mm, διάμετρος 60-90 mm
```

Χαρακτηριστικά:

| Χαρακτηριστικό | Στόχος |
|---|---|
| Διάμετρος | 60-90 mm |
| Πλάτος / μήκος κυλίνδρου | 240-300 mm ενεργό πλάτος συλλογής |
| Υλικό | μαλακό rubber/PU/TPU, όχι σκληρό πλαστικό |
| Άξονας | μακρύς άξονας με στήριξη/ρουλεμάν και στις δύο πλευρές |
| Θέση στο σασί | όσο πιο μπροστά γίνεται, ώστε ο κύλινδρος να πιάνει τη μπάλα πριν τη σπρώξει η βάση |

### Collector Motor

Ζητάμε:

```text
1 τεμάχιο DC gear motor 12V για intake roller
```

Χαρακτηριστικά:

| Χαρακτηριστικό | Στόχος |
|---|---|
| Τάση | 12 V DC |
| Ταχύτητα | περίπου 100-300 RPM |
| Torque | αρκετό για να πιέζει/σηκώνει μπάλα tennis |
| Gearbox | μεταλλικό |
| Encoder | προαιρετικό για collector |

Για collector motor driver:

```text
1 μικρός H-bridge driver ή 1 BTS7960 αν πάρουμε ίδιο driver παντού.
```

## 5. Ασφάλεια Και Ηλεκτρικά

Απαραίτητα:

| Qty | Είδος | Σημειώσεις |
|---:|---|---|
| 1 | Emergency stop switch | Normally-closed, latching mushroom, να κόβει φυσικά την τροφοδοσία στα μοτέρ |
| 1 | Fuse holder | Για την κύρια γραμμή μπαταρίας |
| 2-4 | Ασφάλειες αυτοκινήτου | Main motor fuse 20A αρχικά, electronics fuse 3A-5A, accessory fuse αν χρειαστεί |
| 1 | Κεντρικός διακόπτης | Battery on/off |
| 1 | Start/arm push button | Logic input προς Arduino Mega, δεν αντικαθιστά το E-stop |
| 1 | MPU6050 IMU module | 3-axis gyroscope + 3-axis accelerometer, I2C, Arduino/ROS support, για odometry diagnostics |
| 1 | Power distribution block / terminal blocks | Διανομή +12V/GND προς BTS7960 χωρίς να περνάει ρεύμα από perfboard |
| 1 | Motor-power relay/contactor, optional | Μόνο αν δεν περνάμε το motor current απευθείας από το E-stop/main switch |
| 1 set | Καλώδια σιλικόνης ή automotive | Για ρεύμα μοτέρ/μπαταρίας |
| 1 set | Dupont/JST/terminal connectors | Για logic και sensors |
| 1 set | Heat shrink tubing | Μόνωση συνδέσεων |
| 1 set | Cable ties + αυτοκόλλητες βάσεις | Cable management |

Για μπαταρία, αν αγοράσουμε τώρα:

```text
12V battery pack ή 3S Li-ion/LiPo με BMS/charger, 5-10Ah για πρώτες δοκιμές.
```

Προτεινόμενη on-board μπαταρία για τη βάση:

```text
ECO-WORTHY Lithium Battery 12 V 20 Ah with BMS Protection
LiFePO4 12 V 20 Ah for boats/caravans
```

Χαρακτηριστικά που κρατάμε ως baseline:

| Χαρακτηριστικό | Τιμή / στόχος |
|---|---|
| Χημεία | LiFePO4 |
| Ονομαστική τάση | 12.8 V |
| Χωρητικότητα | 20 Ah |
| BMS | built-in protection |
| Βάρος | περίπου 2.6 kg |
| Διαστάσεις | περίπου 182 x 77 x 170 mm |
| Κύκλοι | 3000+ cycles, έως 15000 ανάλογα χρήση |
| Χρήση | boat, caravan, motorhome, off-grid, όχι starter battery |

Πριν την τελική αγορά επιβεβαιώνουμε:

```text
Maximum continuous discharge current >= 20A
LiFePO4 charger voltage: 14.6V
Terminal type και κατάλληλους ακροδέκτες καλωδίων
```

Προτεινόμενος φορτιστής:

```text
14.6V LiFePO4 charger, 5A προτιμώμενο για ήπια φόρτιση
10A μόνο αν το επιτρέπει ρητά ο κατασκευαστής της μπαταρίας
```

Αν δεν είμαστε έτοιμοι για μπαταρία:

```text
Μπορούμε να κάνουμε πρώτα bench tests με 12V τροφοδοτικό επαρκούς ρεύματος.
```

### Σταθεροποιητές Τάσης / Power Rails

Για τα electronics θέλουμε ξεχωριστό σταθεροποιημένο κλάδο από την ίδια
μπαταρία:

```text
1x 12V DC-DC buck-boost regulator για σταθερό 12V rail, αν χρειαστεί
1x 12V -> 5V buck converter, 5A minimum, για SBC/camera/sensors
```

Ο buck-boost regulator 12V είναι χρήσιμος όταν κάποιο υποσύστημα χρειάζεται
σταθερά 12V, γιατί η LiFePO4 δεν μένει πάντα ακριβώς στα 12V. Το drive motor
power δεν πρέπει να περνάει από μικρό regulator.

### Βασική Καλωδίωση Ισχύος

Η κύρια σύνδεση για τα μοτέρ:

```text
Μπαταρία +
  -> κύρια ασφάλεια Fuse
  -> E-Stop / μανιτάρι ασφαλείας
  -> κεντρικός διακόπτης
  -> Motor Drivers, π.χ. Cytron
  -> Drive motors / collector motor

Μπαταρία -
  -> κοινό ground προς motor drivers, buck converters, controller
```

Για τον ξεχωριστό κλάδο electronics:

```text
Μπαταρία +
  -> μικρότερη ασφάλεια Fuse
  -> buck converter 12V -> 5V
  -> SBC / camera / sensors

Μπαταρία -
  -> κοινό ground
```

Αν χρησιμοποιηθεί 12V buck-boost regulator:

```text
Μπαταρία +
  -> ξεχωριστή ασφάλεια Fuse
  -> 12V buck-boost regulator
  -> σταθερό 12V accessory rail
```

Σημείωση: ο κλάδος που τροφοδοτεί τους motor drivers πρέπει να περνάει από Fuse
και E-Stop. Ο κλάδος electronics μπορεί να έχει δική του μικρότερη ασφάλεια,
ώστε να μην πέφτει όλο το σύστημα από θόρυβο/αιχμές των μοτέρ.

### Καλώδια Και Ακροδέκτες

Για την πρώτη κατασκευή πάρε:

| Qty | Είδος | Χρήση |
|---:|---|---|
| 2-3 m | κόκκινο/μαύρο καλώδιο 2.5 mm² ή 12-14 AWG | μπαταρία, fuse, E-Stop, motor drivers |
| 2-3 m | κόκκινο/μαύρο καλώδιο 1.0-1.5 mm² ή 16-18 AWG | collector motor, accessory 12V, μικρότερα φορτία |
| 2-3 m | καλώδιο 0.25-0.5 mm² ή 22-24 AWG | encoder, PWM, direction, sensors |
| 1 set | ring/spade terminals για τους πόλους της μπαταρίας | σύνδεση στη LiFePO4 |
| 1 set | fork/ring terminals M4/M5 | fuse holder, E-Stop, distribution points |
| 1 set | ferrules | καθαρές συνδέσεις σε screw terminals |
| 1 set | XT60 ή Anderson-style connector | γρήγορη αποσύνδεση μπαταρίας |
| 1 set | WAGO/terminal blocks ή power distribution block | διανομή 12V/GND |
| 1 set | heat shrink tubing | μόνωση |
| 1 set | spiral wrap ή cable sleeve | προστασία καλωδίων |
| 1 set | cable ties + adhesive mounts | cable management |

Προτεινόμενες ασφάλειες για αρχή:

```text
Main motor fuse: 20A ή 25A, ανάλογα με το BMS/motor current
Electronics fuse: 3A-5A
Accessory 12V fuse: 5A-10A, αν μπει buck-boost/accessory rail
```

## 6. Υπολογιστής / On-Board Compute

**Απόφαση: Raspberry Pi 5 (16GB) ως on-board computer** — αντικαθιστά το παλιό
candidate Lenovo i5 mini-PC. Πλήρες σκεπτικό και κόστος στο
[`hardware-bom-el.md`](hardware-bom-el.md).

Σύνοψη επιλεγμένου compute:

```text
Raspberry Pi 5, 16GB LPDDR4X
Broadcom BCM2712, quad-core Cortex-A76 @ 2.4 GHz
PCIe M.2 NVMe board + Silicon Power P34A60 256GB 2280
(`SP256GBP34A60M28AY`) ως υποψήφιο boot drive
Active cooler (υποχρεωτικός σε αυτό το φορτίο)
Τροφοδοσία: 5V/5A — από την μπαταρία μέσω 12V->5V buck converter 5A+
```

Γιατί Pi 5 αντί για i5 mini-PC (το ρομπότ είναι μπαταριοκίνητο/κινούμενο):

| Κριτήριο | Pi 5 16GB | i5 mini-PC | Νικητής |
|---|---|---|---|
| Κατανάλωση | ~5-10W | ~25-45W | **Pi** (3-5x λιγότερο → μικρότερη μπαταρία/μεγαλύτερη αυτονομία) |
| Τροφοδοσία | 5V, απευθείας από buck | 12-19V, θέλει ειδικό DC-DC | **Pi** |
| Μέγεθος/βάρος | μικροσκοπικό | μεγαλύτερο | **Pi** |
| Σύνδεση MCU (Mega/Nano) | USB serial | USB serial | ισοπαλία (USB CDC) |
| Θερμότητα σε κλειστό σασί | εύκολη ψύξη | πιο δύσκολη | **Pi** |
| Compute headroom | αρκετό (+OAK-D offload) | περισσότερο | i5 |
| Dev: Gazebo onboard | όχι (δεν χρειάζεται onboard) | ναι | i5 (μόνο για bench) |

Το μόνο πλεονέκτημα του i5 (compute headroom) ακυρώνεται επειδή το βαρύ vision
(stereo depth + ανίχνευση) γίνεται offload στην **OAK-D** (Myriad X VPU). Δες
`docs/telemetry-architecture-el.md` και την ανάλυση compute budget.

Σημαντική σημείωση τροφοδοσίας:

```text
Το Pi 5 θέλει σταθερά 5V/5A. Πάνω στο robot τροφοδοτείται από την LiFePO4
μέσω του 12V->5V buck converter 5A+ (ήδη στη λίστα). Καλό 5V/5A rail είναι
ΑΠΑΡΑΙΤΗΤΟ για σταθερό NVMe — υποτροφοδοσία προκαλεί throttle/αστάθεια δίσκου.
Το επίσημο 27W PSU του kit είναι μόνο για bench/development.
```

Τι να επιβεβαιώσουμε πριν την τοποθέτηση:

- ότι ο buck converter δίνει σταθερά 5V υπό φορτίο (Pi + OAK-D + LiDAR USB),
- ότι το metal case του kit αφήνει πρόσβαση στις **4 θύρες USB** (OAK-D, LiDAR,
  Mega, Nano), αλλιώς βγάζουμε τη board από το case για το on-robot mount,
  (ο IMU MPU6050 είναι στο I2C του Mega, όχι στα GPIO του Pi — δες hardware-bom-el.md §5),
- ότι ο Silicon Power P34A60 αναγνωρίζεται και περνά boot/reboot/SMART/stress
  test με το συγκεκριμένο PCIe M.2 board (δες validation steps στο BOM),
- αν αντέχει κραδασμούς ή χρειάζεται rubber isolation/standoffs,
- επαρκές Wi-Fi για το telemetry link (αλλιώς external antenna/USB).

## 7. Βίδες, Ροδέλες, Inserts

Πάρε αρκετά, γιατί στο prototype θα λυθούν/δεθούν πολλές φορές.

| Qty | Είδος | Χρήση |
|---:|---|---|
| 30-50 | M5 bolts, διάφορα μήκη | motor pods (x4), collector, handle |
| 30-50 | M5 washers | κάτω από όλες τις κεφαλές |
| 20-30 | M5 nyloc nuts ή T-nuts | αφαιρούμενες συνδέσεις |
| 20-30 | M4 bolts + washers | electronics, μικρά brackets |
| 20 | threaded inserts ή T-nuts | σημεία που θα βγαίνουν συχνά |
| 1 set | ξυλόβιδες 3.5x30 ή 4x30 | ξύλινα rails/νευρώσεις |
| 1 | D4 wood glue | μόνιμες ξύλινες ενισχύσεις |

## 8. Να Μην Αγοραστούν Ακόμα

Μην κλειδώσουμε ακόμα:

- launch flywheel motors
- expensive launcher wheels
- large battery pack για launcher
- pan/tilt μηχανισμούς

Πρώτα θέλουμε:

```text
να κυλάει η βάση,
να πλησιάζει αργά την μπάλα,
να τη βάζει στο funnel,
και ο collector να την ανεβάζει στο hopper.
```

## 9. Σύντομη Λίστα Για Το Ταμείο

Αν ο πωλητής θέλει μόνο τη σύντομη εκδοχή:

```text
1 φύλλο κόντρα πλακέ θαλάσσης σημύδα 12-15 mm, 70x100 cm, κομμένο σύμφωνα με λίστα
4 Metal DC Geared Motor w/Encoder - 12V 122RPM 38Kg.cm: https://grobotronics.com/metal-dc-geared-motor-w-encoder-12v-122rpm-38kg.cm.html
2 BTS7960/IBT-2 motor drivers για brushed DC motors, ένας ανά πλευρά στο πρώτο prototype: https://grobotronics.com/high-power-dc-motor-driver-dual-bts7960-half-bridge-43a.html
προαιρετικά +2 BTS7960 αν χρειαστεί ένα driver ανά μοτέρ
1 Arduino Mega 2560 Rev3 για motion MCU: https://grobotronics.com/arduino-mega-2560-rev3.html
4 driven wheels 180mm rubber/PU ή hubs για τους άξονες
1 DC gear motor 12V 100-300RPM για collector intake roller
1 wide rubber/PU/TPU roller/cylinder 240-300mm x 60-90mm για collector
1 μικρός H-bridge driver για collector ή τρίτος αντίστοιχος driver
production-like εναλλακτική: 2 dual-channel quality drivers ή 4 single-channel quality drivers
1 ECO-WORTHY 12V 20Ah LiFePO4 battery με BMS ή ισοδύναμη 12.8V 20Ah >=20A discharge
1 LiFePO4 charger 14.6V 5A
1 12V DC-DC buck-boost regulator για σταθερό accessory 12V rail, αν χρειαστεί
1 12V -> 5V buck converter 5A+ για SBC/camera/sensors
1 db-tronic Raspberry Pi 5 16GB PCIe M.2 NVMe Set, 64GB Edition
  (M.2 board + active cooler + 27W PSU + metal case), Amazon basket €385,54
1 Silicon Power P34A60 256GB NVMe M.2 PCIe Gen3x4 2280
  (SP256GBP34A60M28AY), Amazon basket €50,99 — boot candidate, ΟΧΙ ακόμη validated
1 emergency stop switch
1 fuse holder + ασφάλειες
κόκκινο/μαύρο καλώδιο 2.5mm² για μπαταρία/motors
καλώδιο 1.0-1.5mm² για collector/accessories
λεπτό καλώδιο 22-24AWG για encoder/control/sensors
ring/spade terminals, ferrules, XT60 ή Anderson connector, heat shrink
M5/M4 βίδες, ροδέλες, T-nuts/threaded inserts
D4 ξυλόκολλα, ξυλόβιδες, heat shrink, καλώδια, connectors
```

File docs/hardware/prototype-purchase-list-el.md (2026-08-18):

# Λίστα Παραγγελίας Πρώτου Prototype

Σκοπός: αγορά υλικών για το πρώτο φυσικό prototype του tennis robot:

```text
ξύλινη βάση + κινητήρια βάση + front collector + βασική ασφάλεια
```

## Sensor Baseline Update

Η νέα baseline επιλογή αισθητήρων είναι:

```text
Waveshare/Slamtec RPLIDAR C1 low 360 LiDAR -> obstacle scan / shadow zones / wall-net-fence clearance / route costmap
OAK-D S2 top camera -> ball detection / hidden ball recovery / ball distance / ball map
Encoders + IMU -> odometry / robot pose
```

Το Waveshare/Slamtec RPLIDAR C1 μπαίνει χαμηλά στο robot για real-time χάρτη εμποδίων, όρια γηπέδου, shadow zones και costmap. Δεν το χρησιμοποιούμε ως αξιόπιστο ball detector, γιατί η μπάλα 6.7 cm δίνει αδύναμο/ασταθές 2D return. Η OAK-D S2 μένει ψηλά ως ο κύριος αισθητήρας για ball detection, depth και targeted look σε περιοχές που το LiDAR δείχνει κρυμμένες ή μπλοκαρισμένες.

Προσθήκη στη λίστα αγοράς electronics/sensors:

| Qty | Είδος | Χρήση |
|---:|---|---|
| 1 | Waveshare/Slamtec RPLIDAR C1 από Amazon.de | Χαμηλό 360° 2D LiDAR για costmap, εμπόδια, shadow zones, φιλέ/τοίχο/φράχτη και ROS 2 navigation |
| 1 | USB/serial cable ή adapter που απαιτεί το C1 kit | Σύνδεση στο SBC / mini PC |
| 1 set | M3/M4 guarded, vibration-isolated lower mounting bracket | Σταθερή χαμηλή οριζόντια τοποθέτηση LiDAR, προστατευμένη από χτυπήματα και χωρίς να κόβεται το 360° scan από ρόδες/funnel |

Πάρε αυτή τη λίστα σε φυσικό κατάστημα ξυλείας/σιδηρικών/ηλεκτρονικών. Οι
διαστάσεις είναι σε mm όπου δεν αναφέρεται κάτι άλλο.

## 1. Ξύλινη Βάση

Υλικό επιλογής:

```text
Κόντρα πλακέ θαλάσσης σημύδα 12-15 mm, φύλλο περίπου 70 x 100 cm
```

Προτίμηση:

```text
15 mm αν υπάρχει.
12 mm αν θέλουμε πιο ελαφριά βάση.
21 mm μόνο αν θέλουμε πολύ στιβαρό αλλά βαρύ prototype.
```

Κοπή:

| Qty | Διαστάσεις | Περιγραφή |
|---:|---|---|
| 1 | 760 x 430 | Κύρια κάτω βάση |
| 2 | 760 x 45 | Μακριά πλαϊνά rails/νευρώσεις |
| 3 | 390 x 45 | Εγκάρσιες νευρώσεις |
| 2 | 180 x 90 | Collector upright plates |
| 2 | 220 x 80 | Hopper/back-plate supports |
| 4 | 120 x 80 | Motor pod reinforcement plates (4WD: one per pod) |
| 2 | 130 x 60 | Stabilizer bracket blocks |
| 2 | 100 x 60 | Handle socket backing plates |

Να υπολογιστεί απώλεια κοπής 3-5 mm ανά πέρασμα δίσκου.

## 2. Κίνηση Βάσης

### Drive Motors

Ζητάμε:

```text
4 τεμάχια DC gear motor 12V με encoder
```

Ιδανικά χαρακτηριστικά:

| Χαρακτηριστικό | Στόχος |
|---|---|
| Τάση | 12 V DC |
| Ταχύτητα | περίπου 120 RPM με τροχό 180 mm |
| Encoder | Ναι, quadrature αν γίνεται |
| Άξονας | 6 mm ή 8 mm D-shaft |
| Rated torque | τουλάχιστον 15-18 kg.cm |
| Stall current | να αναγράφεται στο datasheet |
| Gearbox | μεταλλικό |

Προτεινόμενο συγκεκριμένο μοντέλο για το prototype:

```text
4 τεμάχια Metal DC Geared Motor w/Encoder - 12V 122RPM 38Kg.cm
Link: https://grobotronics.com/metal-dc-geared-motor-w-encoder-12v-122rpm-38kg.cm.html
```

Χαρακτηριστικά του συγκεκριμένου μοτέρ:

| Χαρακτηριστικό | Τιμή |
|---|---|
| Motor type | Brushed DC gear motor με integrated quadrature encoder |
| Rated voltage | 12 V DC |
| No-load speed | 122 RPM |
| Rated torque | 38 kg.cm |
| Encoder | Ναι |
| Wheel target | 170 mm driven wheels (HPI Dirt Buster Block, αγοράστηκαν) |

Αυτό το setup αλλάζει τη βάση σε 4WD differential/skid-steer, χωρίς μπροστινούς
casters. Με τροχό 180 mm και 122 RPM η θεωρητική ταχύτητα είναι περίπου
1.15 m/s χωρίς φορτίο. Το χαμηλότερο RPM και η μεγαλύτερη ροπή είναι πιο
κατάλληλα για σταθερό πρώτο prototype, ειδικά με 4WD skid-steer σε γήπεδο.

Αν δεν υπάρχει με encoder:

```text
Δεν το προτιμάμε για τη βάση. Για αυτόνομη κίνηση και odometry θέλουμε encoder
σε κάθε drive motor ή τουλάχιστον αξιόπιστο encoder ανά πλευρά.
```

Specs επιβεβαιωμένα (DFRobot FIT0403):

- Encoder: ναι, quadrature· gearbox 90:1.
- **Shaft: 6 mm D-shaft** (επιβεβαιωμένο από datasheet + μέτρηση).
- Rated/stall current: ~7 A stall @ 12 V.
- Hub: **απαιτείται adapter 6 mm D-shaft → 24 mm hex** (βλ. ordered-parts.md → Parts To Order).

### Driven Wheels

**ΑΓΟΡΑΣΤΗΚΑΝ:** 4 × HPI Racing Dirt Buster Block Tire S Compound on Black Wheel
(Baja 5B Rear, 170x80 mm, μονταρισμένα με foam inserts). 2 ζευγάρια, μεταχειρισμένα
από RC offroad (8 kg, 90+ χλμ/ώ τελική) — άφθονη αντοχή για συλλέκτη μπαλών.

| Χαρακτηριστικό | Πραγματικό |
|---|---|
| Διάμετρος | 170 mm (radius 0.085 → ενημερώθηκε στο URDF + controllers.yaml) |
| Πλάτος | 80 mm |
| Πάτημα | rubber, S (soft) compound — καλό grip σε clay |
| Hub | **24 mm hex** (πρότυπο Baja 5B) |
| Στήριξη | **24 mm hex adapter, 6 mm bore (D-shaft)** προς τον FIT0403 (βλ. ordered-parts.md → Parts To Order) |

> Επόμενο βήμα: παραγγελία 4× hub adapters **6 mm D-shaft → 24 mm hex**.

### Front Casters

Δεν ζητάμε πλέον front casters για την κύρια κινητήρια βάση:

```text
Νέα baseline: 4 driven wheels, χωρίς casters, για καλύτερη πρόσφυση και πιο
προβλέψιμο έλεγχο σε ταχύτητα/στροφή.
```

Κατάσταση CAD/layout redesign:

```text
Το ενεργό layout ενημερώθηκε σε 4WD skid-steer: δύο αριστεροί και δύο δεξιοί
κινητήριοι τροχοί, με αντίστοιχα motor pods και χώρο για drivers, relay,
καλωδίωση και ασφάλειες. Βλ.
`docs/hardware/chassis-layout-4wd-dual-intake-el.md`. Το manufacturing CAD και
οι τελικές οπές περιμένουν μέτρηση των πραγματικών mounts.
```

## 3. Motor Drivers Και Τροφοδοσία Κίνησης

Ζητάμε:

```text
2 τεμάχια motor driver για brushed DC motor στο πρώτο prototype
```

Budget επιλογή:

```text
BTS7960 / IBT-2 driver, ένας ανά πλευρά
Link: https://grobotronics.com/high-power-dc-motor-driver-dual-bts7960-half-bridge-43a.html
```

Στο πρώτο prototype κάθε BTS7960 οδηγεί τα δύο μοτέρ της ίδιας πλευράς
παράλληλα:

```text
Left BTS7960  -> left front motor + left rear motor
Right BTS7960 -> right front motor + right rear motor
```

Αν δούμε θερμοκρασίες, υπερβολικό ρεύμα, άνισο τράβηγμα ή κακή απόκριση στα
encoders, προσθέτουμε άλλα 2 BTS7960 ώστε να πάμε σε ένα driver ανά μοτέρ.

Prototype drive cost snapshot, 2026-06-21:

| Qty | Είδος | Link | Τιμή μονάδας | Σύνολο |
|---:|---|---|---:|---:|
| 4 | Metal DC Geared Motor w/Encoder - 12V 122RPM 38Kg.cm | https://grobotronics.com/metal-dc-geared-motor-w-encoder-12v-122rpm-38kg.cm.html | 36,00 € | 144,00 € |
| 2 | High-Power DC Motor Driver Dual BTS7960 Half-bridge 43A | https://grobotronics.com/high-power-dc-motor-driver-dual-bts7960-half-bridge-43a.html | 15,90 € | 31,80 € |
| 1 | Arduino Mega 2560 Rev3 | https://grobotronics.com/arduino-mega-2560-rev3.html | 39,00 € | 39,00 € |
|  | **Subtotal κίνησης χωρίς τροχούς/μεταφορικά** |  |  | **214,80 €** |

Το Arduino Mega μπαίνει ως ξεχωριστό motion MCU για encoders, PID ταχύτητας,
acceleration ramps και watchdog. Teensy/ESP32 παραμένουν καλύτερες/εναλλακτικές
επιλογές, αλλά το Mega είναι απλό και διαθέσιμο για πρώτο bring-up.

Να αγοραστεί αφού:

1. κουμπώσει η ξύλινη βάση,
2. τοποθετηθούν motor pods / τροχοί,
3. ξέρουμε το πραγματικό ρεύμα των drive motors,
4. επιβεβαιώσουμε ότι ο driver καλύπτει το stall/peak current των μοτέρ.

Για production-like έκδοση, αντικαθιστούμε τα BTS7960 με 2 ποιοτικούς
dual-channel DC motor drivers ή 4 ποιοτικούς single-channel drivers με
τεκμηριωμένο continuous current, προστασίες και ιδανικά current sensing.
Ο collector μπορεί να χρησιμοποιήσει μικρότερο H-bridge ή άλλο BTS7960 αν
θέλουμε κοινό hardware.

Χαρακτηριστικά:

| Χαρακτηριστικό | Στόχος |
|---|---|
| Motor voltage | 12 V ή 6-27 V range |
| Control | PWM + direction |
| Logic | 3.3 V / 5 V compatible |
| Current | αρκετό για stall current του μοτέρ |
| Cooling | heatsink, να αερίζεται |

Προσοχή: τα “43A” στα BTS7960 είναι συνήθως peak/marketing. Θέλουμε να ξέρουμε
το πραγματικό stall current των μοτέρ και να βάλουμε ασφάλεια.

## 4. Collector Module

### Funnel / Collector Body

Υλικά:

| Qty | Υλικό | Περιγραφή |
|---:|---|---|
| 1 set | PETG/ASA print ή πλαστικό φύλλο 2-3 mm | Funnel side plates και intake guides |
| 2 | compliant side carriages | Πλευρική διαδρομή 8 mm για τους intake wheels |
| 1 | wire-mesh removable basket | Basket v2.1, εσωτερικό 400×280 mm |
| 1 set | μικρές γωνίες ή brackets | Ρυθμιζόμενη σύνδεση funnel/intake carriages |

Διαστάσεις στόχοι:

| Χαρακτηριστικό | Στόχος |
|---|---|
| Funnel mouth width | Να συμφωνεί με το ενεργό URDF/funnel geometry |
| Intake gap | 56 mm nominal, sweep-able |
| Intake wheel radius / height | 60 / 80 mm |
| Basket interior | 400×280 mm, στόχος ~50 μπάλες |

### Dual Intake Wheels

Ζητάμε:

```text
2 τεμάχια compliant rubber/PU/TPU wheels, ακτίνα 60 mm και ύψος 80 mm,
ένα αριστερά και ένα δεξιά του intake corridor
```

Χαρακτηριστικά:

| Χαρακτηριστικό | Στόχος |
|---|---|
| Διάμετρος | 120 mm nominal |
| Ύψος ενεργής επιφάνειας | 80 mm |
| Υλικό | μαλακό rubber/PU/TPU, όχι σκληρό πλαστικό |
| Άξονας | κατακόρυφος, ανεξάρτητος ανά wheel |
| Στήριξη | πλευρικά ενδοτική, travel 8 mm προς τα έξω |
| Θέση | nominal nip x=540 mm, gap 56 mm, tilt 35° |

### Intake Motors

Ζητάμε:

```text
2 πανομοιότυπα DC gear motors 12V, ένα ανά intake wheel
```

Χαρακτηριστικά:

| Χαρακτηριστικό | Στόχος |
|---|---|
| Τάση | 12 V DC |
| Ταχύτητα | GB37Y3530-12V-251R, περίπου 251 RPM no-load |
| Torque | 1.77 N·m stall nominal |
| Gearbox | μεταλλικό |
| Encoder | Hall encoder, απαραίτητο για jam diagnostics |

Για collector motor driver:

```text
Driver με δύο πραγματικά ανεξάρτητα κανάλια ή δύο κατάλληλοι drivers, ώστε οι
τροχοί να περιστρέφονται αντίθετα. Το SparkFun TB6612 του collector πρέπει να
επαληθευτεί ως προς το πραγματικό ρεύμα των δύο μοτέρ πριν χρησιμοποιηθεί.
```

## 5. Ασφάλεια Και Ηλεκτρικά

Απαραίτητα:

| Qty | Είδος | Σημειώσεις |
|---:|---|---|
| 1 | Emergency stop switch | Normally-closed, latching mushroom, να κόβει φυσικά την τροφοδοσία στα μοτέρ |
| 1 | Fuse holder | Για την κύρια γραμμή μπαταρίας |
| 2-4 | Ασφάλειες αυτοκινήτου | Main motor fuse 20A αρχικά, electronics fuse 3A-5A, accessory fuse αν χρειαστεί |
| 1 | Κεντρικός διακόπτης | Battery on/off |
| 1 | Start/arm push button | Logic input προς Arduino Mega, δεν αντικαθιστά το E-stop |
| 1 | MPU6050 IMU module | 3-axis gyroscope + 3-axis accelerometer, I2C, Arduino/ROS support, για odometry diagnostics |
| 1 | Power distribution block / terminal blocks | Διανομή +12V/GND προς BTS7960 χωρίς να περνάει ρεύμα από perfboard |
| 1 | Motor-power relay/contactor, optional | Μόνο αν δεν περνάμε το motor current απευθείας από το E-stop/main switch |
| 1 set | Καλώδια σιλικόνης ή automotive | Για ρεύμα μοτέρ/μπαταρίας |
| 1 set | Dupont/JST/terminal connectors | Για logic και sensors |
| 1 set | Heat shrink tubing | Μόνωση συνδέσεων |
| 1 set | Cable ties + αυτοκόλλητες βάσεις | Cable management |

Για μπαταρία, αν αγοράσουμε τώρα:

```text
12V battery pack ή 3S Li-ion/LiPo με BMS/charger, 5-10Ah για πρώτες δοκιμές.
```

Προτεινόμενη on-board μπαταρία για τη βάση:

```text
ECO-WORTHY Lithium Battery 12 V 20 Ah with BMS Protection
LiFePO4 12 V 20 Ah for boats/caravans
```

Χαρακτηριστικά που κρατάμε ως baseline:

| Χαρακτηριστικό | Τιμή / στόχος |
|---|---|
| Χημεία | LiFePO4 |
| Ονομαστική τάση | 12.8 V |
| Χωρητικότητα | 20 Ah |
| BMS | built-in protection |
| Βάρος | περίπου 2.6 kg |
| Διαστάσεις | περίπου 182 x 77 x 170 mm |
| Κύκλοι | 3000+ cycles, έως 15000 ανάλογα χρήση |
| Χρήση | boat, caravan, motorhome, off-grid, όχι starter battery |

Πριν την τελική αγορά επιβεβαιώνουμε:

```text
Maximum continuous discharge current >= 20A
LiFePO4 charger voltage: 14.6V
Terminal type και κατάλληλους ακροδέκτες καλωδίων
```

Προτεινόμενος φορτιστής:

```text
14.6V LiFePO4 charger, 5A προτιμώμενο για ήπια φόρτιση
10A μόνο αν το επιτρέπει ρητά ο κατασκευαστής της μπαταρίας
```

Αν δεν είμαστε έτοιμοι για μπαταρία:

```text
Μπορούμε να κάνουμε πρώτα bench tests με 12V τροφοδοτικό επαρκούς ρεύματος.
```

### Σταθεροποιητές Τάσης / Power Rails

Για τα electronics θέλουμε ξεχωριστό σταθεροποιημένο κλάδο από την ίδια
μπαταρία:

```text
1x 12V DC-DC buck-boost regulator για σταθερό 12V rail, αν χρειαστεί
1x 12V -> 5V buck converter, 5A minimum, για SBC/camera/sensors
```

Ο buck-boost regulator 12V είναι χρήσιμος όταν κάποιο υποσύστημα χρειάζεται
σταθερά 12V, γιατί η LiFePO4 δεν μένει πάντα ακριβώς στα 12V. Το drive motor
power δεν πρέπει να περνάει από μικρό regulator.

### Βασική Καλωδίωση Ισχύος

Η κύρια σύνδεση για τα μοτέρ:

```text
Μπαταρία +
  -> κύρια ασφάλεια Fuse
  -> E-Stop / μανιτάρι ασφαλείας
  -> κεντρικός διακόπτης
  -> Motor Drivers, π.χ. Cytron
  -> Drive motors / collector motor

Μπαταρία -
  -> κοινό ground προς motor drivers, buck converters, controller
```

Για τον ξεχωριστό κλάδο electronics:

```text
Μπαταρία +
  -> μικρότερη ασφάλεια Fuse
  -> buck converter 12V -> 5V
  -> SBC / camera / sensors

Μπαταρία -
  -> κοινό ground
```

Αν χρησιμοποιηθεί 12V buck-boost regulator:

```text
Μπαταρία +
  -> ξεχωριστή ασφάλεια Fuse
  -> 12V buck-boost regulator
  -> σταθερό 12V accessory rail
```

Σημείωση: ο κλάδος που τροφοδοτεί τους motor drivers πρέπει να περνάει από Fuse
και E-Stop. Ο κλάδος electronics μπορεί να έχει δική του μικρότερη ασφάλεια,
ώστε να μην πέφτει όλο το σύστημα από θόρυβο/αιχμές των μοτέρ.

### Καλώδια Και Ακροδέκτες

Για την πρώτη κατασκευή πάρε:

| Qty | Είδος | Χρήση |
|---:|---|---|
| 2-3 m | κόκκινο/μαύρο καλώδιο 2.5 mm² ή 12-14 AWG | μπαταρία, fuse, E-Stop, motor drivers |
| 2-3 m | κόκκινο/μαύρο καλώδιο 1.0-1.5 mm² ή 16-18 AWG | collector motor, accessory 12V, μικρότερα φορτία |
| 2-3 m | καλώδιο 0.25-0.5 mm² ή 22-24 AWG | encoder, PWM, direction, sensors |
| 1 set | ring/spade terminals για τους πόλους της μπαταρίας | σύνδεση στη LiFePO4 |
| 1 set | fork/ring terminals M4/M5 | fuse holder, E-Stop, distribution points |
| 1 set | ferrules | καθαρές συνδέσεις σε screw terminals |
| 1 set | XT60 ή Anderson-style connector | γρήγορη αποσύνδεση μπαταρίας |
| 1 set | WAGO/terminal blocks ή power distribution block | διανομή 12V/GND |
| 1 set | heat shrink tubing | μόνωση |
| 1 set | spiral wrap ή cable sleeve | προστασία καλωδίων |
| 1 set | cable ties + adhesive mounts | cable management |

Προτεινόμενες ασφάλειες για αρχή:

```text
Main motor fuse: 20A ή 25A, ανάλογα με το BMS/motor current
Electronics fuse: 3A-5A
Accessory 12V fuse: 5A-10A, αν μπει buck-boost/accessory rail
```

## 6. Υπολογιστής / On-Board Compute

**Απόφαση: Raspberry Pi 5 (16GB) ως on-board computer** — αντικαθιστά το παλιό
candidate Lenovo i5 mini-PC. Πλήρες σκεπτικό και κόστος στο
[`hardware-bom-el.md`](hardware-bom-el.md).

Σύνοψη επιλεγμένου compute:

```text
Raspberry Pi 5, 16GB LPDDR4X
Broadcom BCM2712, quad-core Cortex-A76 @ 2.4 GHz
PCIe M.2 NVMe board + Silicon Power P34A60 256GB 2280
(`SP256GBP34A60M28AY`) ως υποψήφιο boot drive
Active cooler (υποχρεωτικός σε αυτό το φορτίο)
Τροφοδοσία: 5V/5A — από την μπαταρία μέσω 12V->5V buck converter 5A+
```

Γιατί Pi 5 αντί για i5 mini-PC (το ρομπότ είναι μπαταριοκίνητο/κινούμενο):

| Κριτήριο | Pi 5 16GB | i5 mini-PC | Νικητής |
|---|---|---|---|
| Κατανάλωση | ~5-10W | ~25-45W | **Pi** (3-5x λιγότερο → μικρότερη μπαταρία/μεγαλύτερη αυτονομία) |
| Τροφοδοσία | 5V, απευθείας από buck | 12-19V, θέλει ειδικό DC-DC | **Pi** |
| Μέγεθος/βάρος | μικροσκοπικό | μεγαλύτερο | **Pi** |
| Σύνδεση MCU (Mega/Nano) | USB serial | USB serial | ισοπαλία (USB CDC) |
| Θερμότητα σε κλειστό σασί | εύκολη ψύξη | πιο δύσκολη | **Pi** |
| Compute headroom | αρκετό (+OAK-D offload) | περισσότερο | i5 |
| Dev: Gazebo onboard | όχι (δεν χρειάζεται onboard) | ναι | i5 (μόνο για bench) |

Το μόνο πλεονέκτημα του i5 (compute headroom) ακυρώνεται επειδή το βαρύ vision
(stereo depth + ανίχνευση) γίνεται offload στην **OAK-D** (Myriad X VPU). Δες
`docs/process/telemetry-architecture-el.md` και την ανάλυση compute budget.

Σημαντική σημείωση τροφοδοσίας:

```text
Το Pi 5 θέλει σταθερά 5V/5A. Πάνω στο robot τροφοδοτείται από την LiFePO4
μέσω του 12V->5V buck converter 5A+ (ήδη στη λίστα). Καλό 5V/5A rail είναι
ΑΠΑΡΑΙΤΗΤΟ για σταθερό NVMe — υποτροφοδοσία προκαλεί throttle/αστάθεια δίσκου.
Το επίσημο 27W PSU του kit είναι μόνο για bench/development.
```

Τι να επιβεβαιώσουμε πριν την τοποθέτηση:

- ότι ο buck converter δίνει σταθερά 5V υπό φορτίο (Pi + OAK-D + LiDAR USB),
- ότι το metal case του kit αφήνει πρόσβαση στις **4 θύρες USB** (OAK-D, LiDAR,
  Mega, Nano), αλλιώς βγάζουμε τη board από το case για το on-robot mount,
  (ο IMU MPU6050 είναι στο I2C του Mega, όχι στα GPIO του Pi — δες hardware-bom-el.md §5),
- ότι ο Silicon Power P34A60 αναγνωρίζεται και περνά boot/reboot/SMART/stress
  test με το συγκεκριμένο PCIe M.2 board (δες validation steps στο BOM),
- αν αντέχει κραδασμούς ή χρειάζεται rubber isolation/standoffs,
- επαρκές Wi-Fi για το telemetry link (αλλιώς external antenna/USB).

## 7. Βίδες, Ροδέλες, Inserts

Πάρε αρκετά, γιατί στο prototype θα λυθούν/δεθούν πολλές φορές.

| Qty | Είδος | Χρήση |
|---:|---|---|
| 30-50 | M5 bolts, διάφορα μήκη | motor pods (x4), collector, handle |
| 30-50 | M5 washers | κάτω από όλες τις κεφαλές |
| 20-30 | M5 nyloc nuts ή T-nuts | αφαιρούμενες συνδέσεις |
| 20-30 | M4 bolts + washers | electronics, μικρά brackets |
| 20 | threaded inserts ή T-nuts | σημεία που θα βγαίνουν συχνά |
| 1 set | ξυλόβιδες 3.5x30 ή 4x30 | ξύλινα rails/νευρώσεις |
| 1 | D4 wood glue | μόνιμες ξύλινες ενισχύσεις |

## 8. Να Μην Αγοραστούν Ακόμα

Μην κλειδώσουμε ακόμα:

- launch flywheel motors
- expensive launcher wheels
- large battery pack για launcher
- pan/tilt μηχανισμούς

Πρώτα θέλουμε:

```text
να κυλάει η βάση,
να πλησιάζει αργά την μπάλα,
να τη βάζει στο funnel,
και ο collector να την ανεβάζει στο hopper.
```

## 9. Σύντομη Λίστα Για Το Ταμείο

Αν ο πωλητής θέλει μόνο τη σύντομη εκδοχή:

```text
1 φύλλο κόντρα πλακέ θαλάσσης σημύδα 12-15 mm, 70x100 cm, κομμένο σύμφωνα με λίστα
4 Metal DC Geared Motor w/Encoder - 12V 122RPM 38Kg.cm: https://grobotronics.com/metal-dc-geared-motor-w-encoder-12v-122rpm-38kg.cm.html
2 BTS7960/IBT-2 motor drivers για brushed DC motors, ένας ανά πλευρά στο πρώτο prototype: https://grobotronics.com/high-power-dc-motor-driver-dual-bts7960-half-bridge-43a.html
προαιρετικά +2 BTS7960 αν χρειαστεί ένα driver ανά μοτέρ
1 Arduino Mega 2560 Rev3 για motion MCU: https://grobotronics.com/arduino-mega-2560-rev3.html
4 driven wheels 180mm rubber/PU ή hubs για τους άξονες
1 DC gear motor 12V 100-300RPM για collector intake roller
1 wide rubber/PU/TPU roller/cylinder 240-300mm x 60-90mm για collector
1 μικρός H-bridge driver για collector ή τρίτος αντίστοιχος driver
production-like εναλλακτική: 2 dual-channel quality drivers ή 4 single-channel quality drivers
1 ECO-WORTHY 12V 20Ah LiFePO4 battery με BMS ή ισοδύναμη 12.8V 20Ah >=20A discharge
1 LiFePO4 charger 14.6V 5A
1 12V DC-DC buck-boost regulator για σταθερό accessory 12V rail, αν χρειαστεί
1 12V -> 5V buck converter 5A+ για SBC/camera/sensors
1 db-tronic Raspberry Pi 5 16GB PCIe M.2 NVMe Set, 64GB Edition
  (M.2 board + active cooler + 27W PSU + metal case), Amazon basket €385,54
1 Silicon Power P34A60 256GB NVMe M.2 PCIe Gen3x4 2280
  (SP256GBP34A60M28AY), Amazon basket €50,99 — boot candidate, ΟΧΙ ακόμη validated
1 emergency stop switch
1 fuse holder + ασφάλειες
κόκκινο/μαύρο καλώδιο 2.5mm² για μπαταρία/motors
καλώδιο 1.0-1.5mm² για collector/accessories
λεπτό καλώδιο 22-24AWG για encoder/control/sensors
ring/spade terminals, ferrules, XT60 ή Anderson connector, heat shrink
M5/M4 βίδες, ροδέλες, T-nuts/threaded inserts
D4 ξυλόκολλα, ξυλόβιδες, heat shrink, καλώδια, connectors
```

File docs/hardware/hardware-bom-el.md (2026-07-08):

# Hardware BOM — On-Board Compute (EL)

> Απόφαση: **Raspberry Pi 5 (16GB)** ως on-board computer του ρομπότ,
> **αντικαθιστά** το παλιό candidate Lenovo i5 mini-PC. Το βαρύ vision
> (stereo depth + ανίχνευση) γίνεται offload στην **OAK-D** (Myriad X VPU),
> οπότε η CPU του Pi μένει ελεύθερη για slam_toolbox + Nav2 + classical CV.
>
> Σχετικά: `prototype-purchase-list-el.md` §6, `telemetry-architecture-el.md`.

---

## 1. Απόφαση: Pi 5 vs i5 mini-PC

Το ρομπότ είναι **μπαταριοκίνητο και κινούμενο**, οπότε η τιμή αγοράς είναι
δευτερεύουσα — κρίνουν τα watt, τα ampere και τα γραμμάρια.

| Κριτήριο | Pi 5 16GB | i5 mini-PC | Νικητής |
|---|---|---|---|
| Κατανάλωση | ~5-10W | ~25-45W | **Pi** (3-5x λιγότερο) |
| Τροφοδοσία | 5V, απευθείας από buck | 12-19V, ειδικό DC-DC | **Pi** |
| Μέγεθος/βάρος | μικροσκοπικό | μεγαλύτερο | **Pi** |
| Σύνδεση MCU (Mega/Nano) | USB serial | USB serial | ισοπαλία (USB CDC και στα δύο) |
| Θερμότητα σε κλειστό σασί | εύκολη ψύξη | δύσκολη | **Pi** |
| Compute headroom | αρκετό (+OAK-D offload) | περισσότερο | i5 |
| Gazebo onboard | όχι (περιττό onboard) | ναι | i5 (μόνο bench) |

Το μόνο πλεονέκτημα του i5 (headroom) ακυρώνεται από το OAK-D offload. Επιπλέον
ο i5 με 30-40W αντί 8W σημαίνει 3-5x μεγαλύτερη/βαρύτερη μπαταρία για ίδια
αυτονομία — μόνιμος φόρτος που κουβαλιέται για πάντα.

**Πότε θα γυρίζαμε στον i5:** μόνο αν το ρομπότ ήταν tethered (σταθερή τροφοδοσία)
ή αν τρέχαμε βαρύ 3D perception / onboard learning ΧΩΡΙΣ offload. Κανένα δεν ισχύει.

---

## 2. Compute budget — γιατί το Pi 5 αρκεί

| Φορτίο | Πού τρέχει | Βάρος στο Pi |
|---|---|---|
| 2D LiDAR `/scan` | host | αμελητέο (KB/s) |
| slam_toolbox (map→base_link TF) | host | μέτριο, OK σε Pi (τρέχει & σε Pi 4) |
| Survey FSM + extraction | host | ελαφρύ (5Hz, max 1500 σημεία) |
| Nav2 local costmap + avoidance | host | μέτριο — χρήση **DWB/Regulated Pure Pursuit**, ΟΧΙ MPPI |
| Stereo depth (`/camera/depth`) | **OAK-D VPU** | offloaded (μηδέν στο host) |
| Classical CV (HSV/Canny/Hough) | host | ελαφρύ· throttle στα ~10fps |
| Telemetry writes (5Hz JSON) | host + NVMe | ελαφρύ (γι' αυτό NVMe, όχι SD) |

Obstacle avoidance (π.χ. άνθρωπος στο court): reactive LiDAR e-stop + Nav2 local
costmap με ελαφρύ controller — μέσα στο budget του Pi 5.

---

## 3. BOM — Compute stack

| # | Είδος | Σημειώσεις | Ενδεικτικό κόστος |
|---|---|---|---|
| 1 | **db-tronic Raspberry Pi 5 16GB PCIe M.2 NVMe Set — 64GB Edition** | Επιλεγμένο στο Amazon basket. Περιλαμβάνει Pi 5 16GB, PCIe M.2 NVMe board, active cooler, metal housing και 27W PSU. Η «64GB Edition» αφορά το αποθηκευτικό μέσο του kit· να επιβεβαιωθεί το ακριβές περιεχόμενο κατά την παραλαβή. | **€385,54** |
| 2 | **Silicon Power P34A60 256GB NVMe M.2 PCIe Gen3x4 2280 SSD** (`SP256GBP34A60M28AY`) | Επιλεγμένο ξεχωριστά ως NVMe boot drive. Δεν είναι ο επίσημος Raspberry Pi SSD· απαιτείται recognition/boot/stress test με το M.2 board πριν θεωρηθεί validated για το robot. | **€50,99** |
| 3 | 12V→5V buck converter 5A+ | On-robot τροφοδοσία Pi από LiFePO4 (ήδη στη βασική λίστα) | ~€8-12 |
| — | (microSD του kit) | Μόνο για flashing/εφεδρεία — **όχι** ως boot drive | περιλαμβάνεται |
| — | (27W PSU του kit) | Μόνο για bench/development — όχι on-robot | περιλαμβάνεται |
| **Σύνολο επιλεγμένου Amazon basket** | | | **€436,53** |
| **Σύνολο compute με on-robot buck** | | | **~€444,53-448,53** |

> Τιμές από το Amazon shopping basket της 28/06/2026. Τα είδη είναι
> **επιλεγμένα αλλά όχι ακόμη καταγεγραμμένα ως παραγγελμένα**.

---

## 4. NVMe SSD — συμβατότητα (κρίσιμο)

Το Pi 5 έχει γνωστά θέματα recognition με κάποιους NVMe controllers. **Μη πάρεις
τυχαίο δίσκο.**

**Top (χαμηλότερο ρίσκο):** Επίσημος Raspberry Pi SSD (256/512GB) — φτιαγμένος για το M.2 HAT+.

**Τρέχουσα επιλογή καλαθιού:** Silicon Power P34A60 256GB
(`SP256GBP34A60M28AY`). Δεν υπάρχει ακόμη project-specific validation. Πριν
χρησιμοποιηθεί ως κύριο boot drive:

1. επιβεβαίωση ότι εμφανίζεται στα `lspci` / `lsblk`,
2. cold-boot και reboot δοκιμές,
3. έλεγχος SMART,
4. συνεχόμενο read/write stress test,
5. επανάληψη με το 27W PSU και αργότερα με το on-robot 5V/5A buck.

**Γενικά ασφαλείς:** Samsung 980 / 990 EVO, Crucial P3.

**Απόφυγε (reported I/O errors / no recognition):** Kingston NV2 / NV3,
WD Black SN770 / SN850X. Τα WD γενικά είναι hit-or-miss στο Pi 5.

Setup σημειώσεις:
- Μόνο **M.2 NVMe Key-M** (όχι SATA, όχι Key-B).
- Το HAT δέχεται μεγέθη **2230 / 2242 / 2280**.
- Νέος δίσκος θέλει partition + format πριν χρησιμοποιηθεί.
- Αν δεν αναγνωρίζεται, βάλε `dtparam=pciex1_gen=3` στο `config.txt`.
- **5V/5A σταθερό** είναι απαραίτητο για σταθερό NVMe — υποτροφοδοσία → throttle/αστάθεια.

---

## 5. Σύνδεση με MCU (Mega / Nano / launcher)

Ο Pi μιλάει στους Arduino μέσω **USB serial (CDC, 115200 baud)** — host-agnostic,
ίδιο με PC. Ο IMU (MPU6050) είναι στο **I2C του Arduino Mega** (μέσω perfboard),
**όχι** στα GPIO του Pi. Άρα ο Pi χρειάζεται κυρίως **USB πρόσβαση**, όχι GPIO.

Η ασφάλεια/real-time loop ζει στους Arduino (Mega boots DISARMED, command timeout,
encoder sanity), ανεξάρτητα από το Pi. Ο Pi στέλνει μόνο high-level εντολές — δεν
κλείνει real-time βρόχο πάνω από serial.

**USB port budget (κρίσιμο):**

| Συσκευή | Θύρα |
|---|---|
| OAK-D S2 | USB3 |
| RPLIDAR C1 | USB (ttyUSB0) |
| Arduino Mega (driving) | USB (ttyACM) |
| Arduino Nano (collector) | USB (ttyACM) |

= **4 συσκευές / 4 θύρες** στο Pi 5 (2×USB3 + 2×USB2). Γεμίζουν όλες.
**Με το flywheel/launcher MCU (Phase 2) → χρειάζεται powered USB hub.**

## 6. Σημεία προσοχής στην ενσωμάτωση

- **udev rules (απαραίτητο).** Σε Linux ο Mega/Nano εναλλάσσουν `ttyACM0`/`ttyACM1`
  σε κάθε boot. Κλείδωσέ τους σε σταθερά ονόματα (π.χ. `/dev/ttyMEGA`, `/dev/ttyNANO`)
  βάσει USB serial number, αλλιώς το driving node μπορεί να ανοίξει τον collector.
- **USB3 ↔ Wi-Fi interference.** Το USB3 της OAK-D εκπέμπει θόρυβο στα 2.4GHz που
  χτυπά το onboard Wi-Fi (το telemetry link). Κοντό/θωρακισμένο USB3 καλώδιο,
  κεραία μακριά, ή 5GHz Wi-Fi.
- **USB access στο metal case.** Το case του kit πρέπει να αφήνει πρόσβαση στις 4
  θύρες USB. Αν όχι → βγάζουμε τη board από το case για on-robot mount, με standoffs.
- **Τροφοδοσία on-robot:** Pi από LiFePO4 → 12V→5V buck 5A+. Το 27W PSU μένει για bench.
  Πρόσεξε το συνολικό 5V budget: Pi + OAK-D (USB-powered, λαίμαργη) + LiDAR + Arduinos.
  Powered USB hub βοηθά και εδώ.
- **NVMe boot, όχι SD:** οι microSD κάρτες κάνουν corruption σε Pi με συχνά μικρά
  writes + απότομες διακοπές ρεύματος — ακριβώς το προφίλ του ρομπότ (5Hz telemetry
  + battery). Γι' αυτό boot από NVMe.
- **Vibration:** rubber isolation/standoffs αν χρειαστεί.
- **Wi-Fi:** για το telemetry link· external antenna/USB αν το onboard δεν φτάνει.

## 7. Flywheel / launcher (Phase 2)

Ξεχωριστό module (dual flywheels + ESCs), προς το παρόν deferred. Control:

- **Ξεχωριστός MCU (προτεινόμενο):** απομονώνει το safety-critical launcher από το
  drive loop → +1 USB συσκευή → **powered USB hub**.
- **Spare PWM pins του Mega:** τα ESCs ελέγχονται με servo-style PWM και ο Mega έχει
  άφθονα PWM pins → κανένα επιπλέον USB, αλλά μπλέκει launcher με drive MCU.

---

## 8. Τι ΔΕΝ αλλάζει

Το υπόλοιπο σύστημα (μπαταρία LiFePO4, motor drivers BTS7960, Arduino Mega motion
MCU, buck converters, OAK-D, LiDAR) παραμένει ως έχει στο `prototype-purchase-list-el.md`.
Μόνο το on-board compute αλλάζει από i5 mini-PC σε Pi 5 16GB.

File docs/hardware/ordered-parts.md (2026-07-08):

# Ordered Parts

Παραγγελία Skroutz: `260531-7129740`  
Ημερομηνία παραγγελίας: `31/05/2026 11:51 μ.μ.`  
Τρόπος πληρωμής: Κάρτα `****7340`

## Parts

| # | Part | Κατηγορία | Ποσότητα | Τιμή μονάδας | Σύνολο | Πωλητής | Εκτιμώμενη παραλαβή | Κατάσταση |
|---:|---|---|---:|---:|---:|---|---|---|
| 1 | DFRobot Κινητήρας DC 12V 251rpm (FIT0186) | Collector | 1 | 23,60 € | 23,60 € | Grobotronics | Τρίτη | Παραλήφθηκε |
| 2 | Male to Male - Pack of 10 Καλώδιο Jumper - 0.15m | Collector | 2 | 1,80 € | 3,60 € | Grobotronics | Τρίτη | Παραλήφθηκε |
| 3 | Haitronic Nano V3 ATmega328P USB cable Board για Arduino | Collector | 1 | 5,70 € | 5,70 € | Hamradio | Έως Τετ, 03 Ιουν | Παραλήφθηκε |
| 4 | MB102 Breadboard Πλακέτα 400 Θέσεων 83x55mm | Collector | 1 | 2,50 € | 2,50 € | A-store | Έως Τετ, 03 Ιουν | Παραλήφθηκε |
| 5 | Power Supply 100-240V 12V 2A 24W 5.5x2.5mm Connector Without Power Cable | Collector | 1 | 6,40 € | 6,40 € | Vexio | Πέμ, 04 Ιουν - Τετ, 10 Ιουν | Παραλήφθηκε |
| 6 | SparkFun Motor Driver - Dual TB6612FNG | Collector | 1 | 6,50 € | 6,50 € | Radel S.A. | Τρίτη | Παραλήφθηκε |

## Additional Ordered Parts

| # | Part | Κατηγορία | Ποσότητα | Τιμή μονάδας | Σύνολο | Πωλητής | Εκτιμώμενη παραλαβή | Κατάσταση |
|---:|---|---|---:|---:|---:|---|---|---|
| 7 | Waveshare Slamtec RPLIDAR C1 Laser Ranging Sensor, 360° Omnidirectional Lidar, Millimetre Level High Definition, Anti-Interference and Anti-Adhesion, Compact and Easy to Integrate | Sensors / Navigation LiDAR | 1 | 83,35 € | 83,35 € | TBD | Παρασκευή | Αγοράστηκε — εκκρεμεί παράδοση (δεν έχει έρθει ακόμα) |
| 8 | HPI Racing Dirt Buster Block Tire S Compound on Black Wheel (Baja 5B Rear, 170x80 mm, mounted w/ foam inserts, 24 mm hex) — 1 ζευγάρι | Drive / Wheels | 2 | TBD | TBD | RC offroad (μεταχειρισμένα) | Παραλήφθηκε | Αγοράστηκε |
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

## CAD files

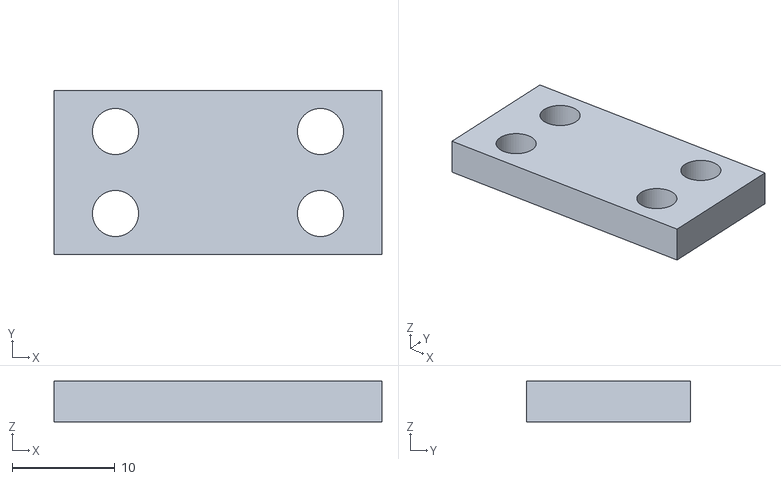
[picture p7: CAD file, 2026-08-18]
cad/basket-bin-v2/stl-segments/joiner_plate.stl
32.0 x 16.0 x 4.00

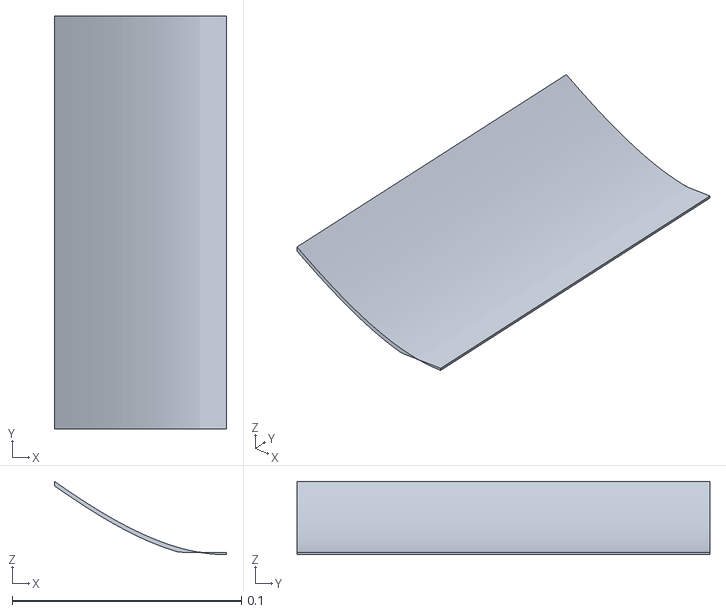
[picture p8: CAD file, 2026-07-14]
gazebo/models/tennis_robot/meshes/curved_scoop.stl
0.075 x 0.18 x 0.032

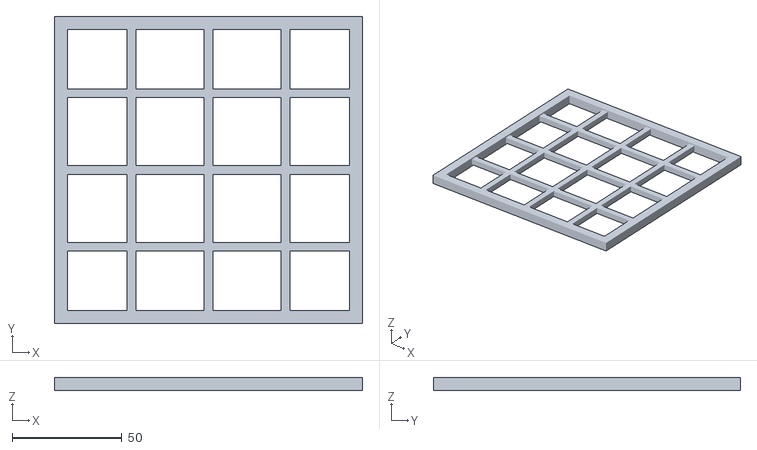
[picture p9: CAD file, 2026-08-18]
cad/basket-bin-v2/stl-segments/management_tray_tile.stl
140.4 x 140.0 x 6.00

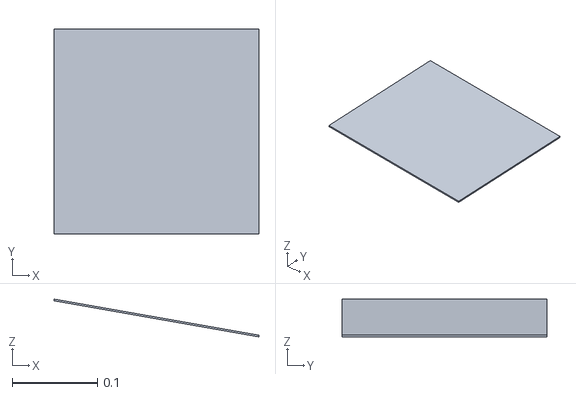
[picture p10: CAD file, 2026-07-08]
gazebo/models/tennis_robot/meshes/scooper_wedge.stl
0.24 x 0.24 x 0.0443

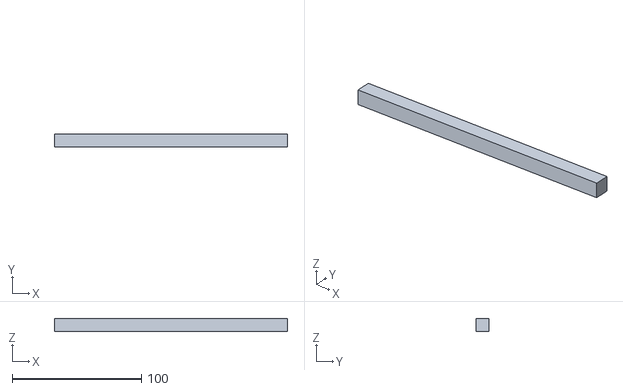
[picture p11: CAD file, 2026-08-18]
cad/basket-bin-v2/stl-segments/center_lip.stl
180.0 x 10.0 x 10.0

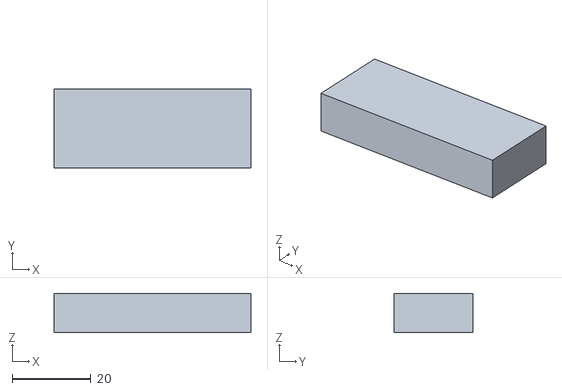
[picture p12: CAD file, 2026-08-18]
cad/basket-bin-v2/stl-segments/corner_guard.stl
50.0 x 20.0 x 10.0

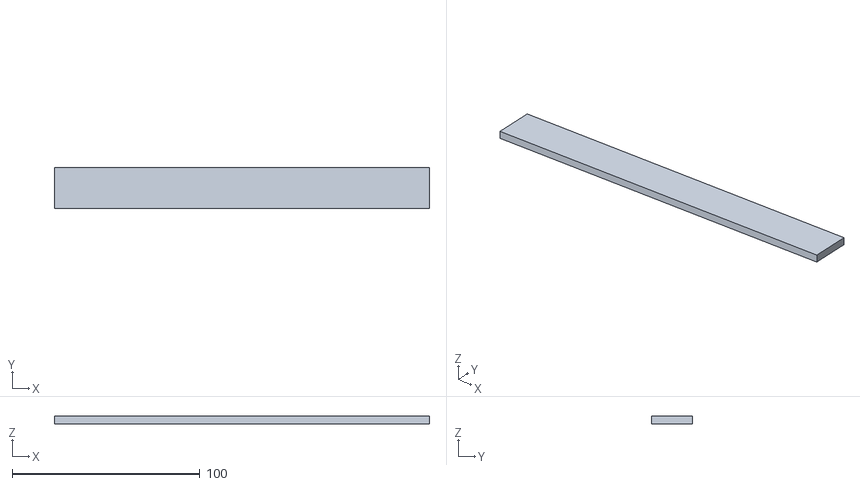
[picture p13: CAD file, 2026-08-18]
cad/basket-bin-v2/stl-segments/side_flange_segment.stl
200.0 x 22.0 x 4.00

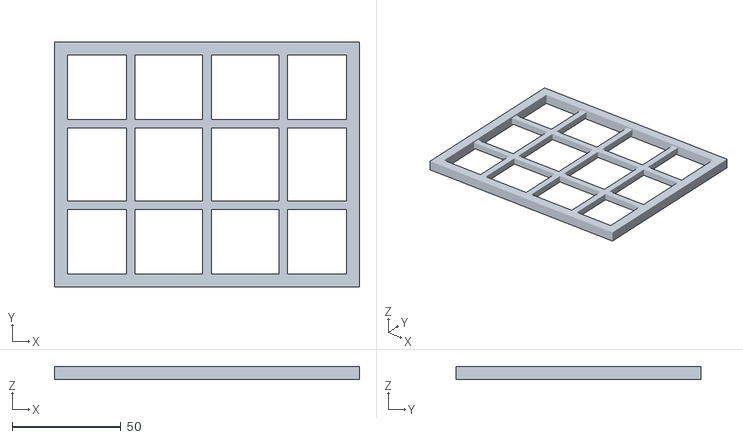
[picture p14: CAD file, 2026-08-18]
cad/basket-bin-v2/stl-segments/rear_wall_tile.stl
140.0 x 112.5 x 6.00

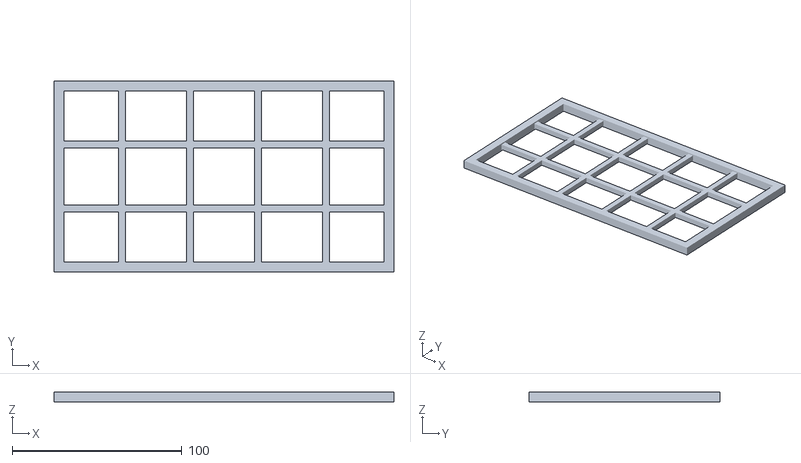
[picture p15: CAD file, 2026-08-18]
cad/basket-bin-v2/stl-segments/side_wall_tile.stl
200.0 x 112.5 x 6.00

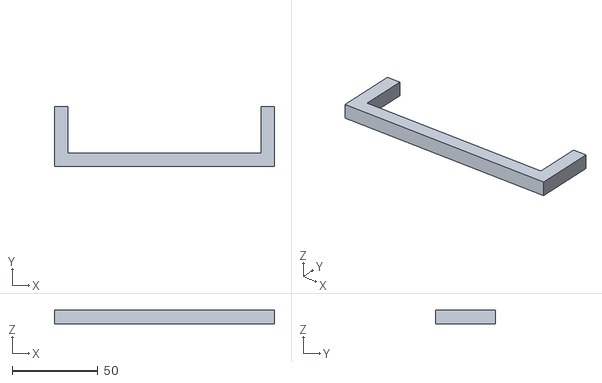
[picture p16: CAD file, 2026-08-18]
cad/basket-bin-v2/stl-segments/carry_handle.stl
128.0 x 35.0 x 8.00

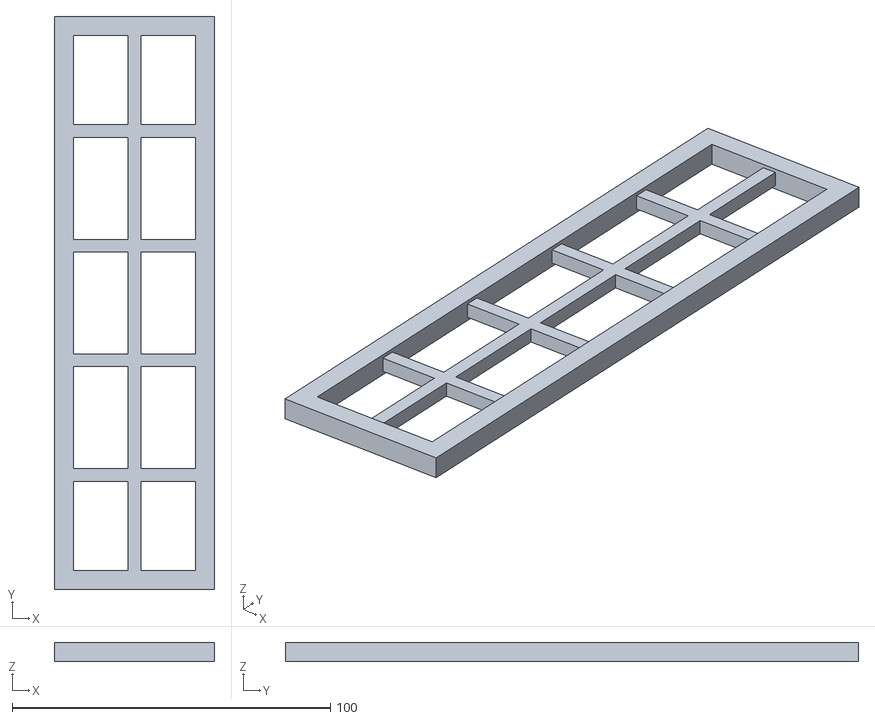
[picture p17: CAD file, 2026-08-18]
cad/basket-bin-v2/stl-segments/receiving_chute_tile.stl
50.2 x 180.0 x 6.00

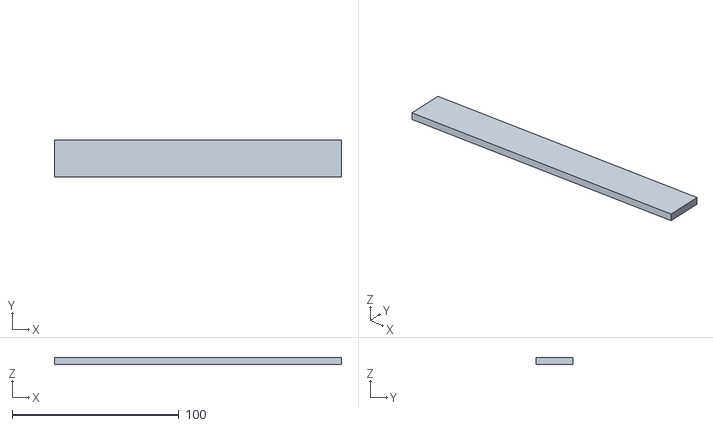
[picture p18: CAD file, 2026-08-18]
cad/basket-bin-v2/stl-segments/rear_flange_segment.stl
172.0 x 22.0 x 4.00

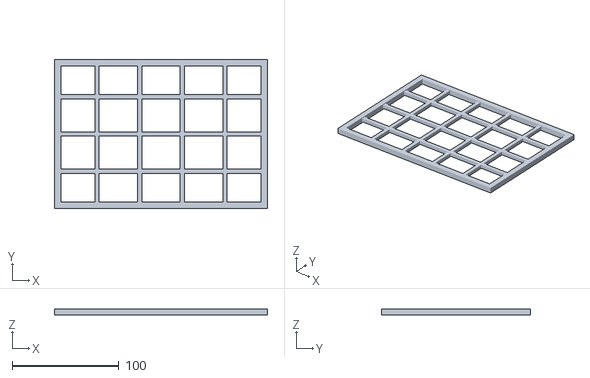
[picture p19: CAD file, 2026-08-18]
cad/basket-bin-v2/stl-segments/floor_tile.stl
200.0 x 140.0 x 6.00

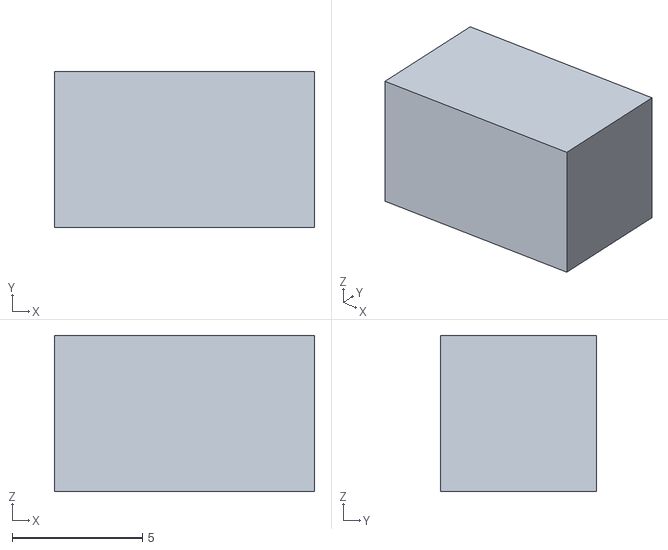
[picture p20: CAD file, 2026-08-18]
cad/basket-bin-v2/stl-segments/drop_strut.stl
10.0 x 6.00 x 6.00

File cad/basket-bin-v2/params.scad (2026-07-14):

// Basket bin v2.1 + entry hood — validated dimensions.
//
// Single source of truth for every file in this directory.
// All values in mm, GROUND frame (z=0 at court surface), robot +x forward.
// Sources: docs/basket-bin-redesign-spec-el.md,
//          ros2_ws/src/tennis_robot/urdf/components/basket.urdf.xacro,
//          debug log #45-#56 (docs/intake-debug-log-el.md).
// Do not change a value here without re-validating in the Gazebo bench.

// ---- Bin interior (spec §2) ----
bin_rear_x       = 20;    // rear interior plane
bin_front_x      = 420;   // front interior plane = retention boundary
bin_half_width   = 140;   // interior half width (280 total)
floor_top_z      = 25;    // sunken floor top (20 mm ground clearance below)
floor_thickness  = 5;
wall_top_z       = 250;   // rim height (below lidar plane 498)
wall_thickness   = 10;    // effective wall envelope in sim

// ---- Load-management tray (spec §2, log #54 low_transition) ----
mgmt_run         = 140;   // rear edge x = bin_front_x - mgmt_run = 280
mgmt_rise        = 10;    // tray top: 25 @ x280 -> 35 @ x420 (~4.1 deg)

// ---- Receiving chute (spec §2) ----
recv_run         = 50;    // x 420 -> 470
recv_rise        = 5;     // top: 35 @ x420 -> 40 @ x470
recv_half_width  = 90;    // 180 mm launch channel

// ---- Front retention (log #51/#52) ----
entry_half_width = 90;    // launch opening half width
guard_height     = 20;    // corner guards, z 25..45, y 90..140 each side
center_lip_height = 10;   // fixed centre lip, z 25..35 (log #52 -> low-transition)

// ---- Entry hood (log #54-#56, now sim default) ----
hood_rear_overhang    = 40;   // roof rear x = bin_front_x - 40 = 380
hood_rear_clearance_z = 120;  // roof underside @ rear edge
hood_front_clearance_z = 135; // roof underside @ front edge (x 470)
hood_cheek_thickness  = 5;

// ---- Wire mesh construction (spec §2: hopper-style mesh) ----
wire_d     = 4;    // mesh wire
frame_d    = 6;    // panel perimeter rod
mesh_pitch = 40;   // grid opening <= 40 (ball 66 cannot pass)

// ---- Chassis context (reference only, spec §3-§4) ----
plate_top_z     = 52;
plate_thickness = 14;
plate_half_len  = 460;   // 920 x 580 chassis
plate_half_wid  = 290;
open_rear_x     = 10;    // plate opening x 10..460, y +/-150
open_front_x    = 460;
open_half_wid   = 150;
flange_width    = 22;    // bin rests on this ring, on the plate top
flange_thickness = 4;

// ---- Sensors / references ----
ir_x       = 445;   // confirmation beam through the chute midpoint
ir_z       = 70.5;
ir_mount_y = 155;   // sensor bodies on the chassis, outside the bin
ball_d     = 66;

// Battery bay (spec §4): 198 x 166 x 170, x -226..-60, centered in y
batt_size  = [166, 198, 170];
batt_min_x = -226;

// Derived (do not edit)
bin_length   = bin_front_x - bin_rear_x;           // 400
wall_height  = wall_top_z - floor_top_z;           // 225
mgmt_rear_x  = bin_front_x - mgmt_run;             // 280
mgmt_angle   = atan2(mgmt_rise, mgmt_run);         // ~4.09 deg
recv_front_x = bin_front_x + recv_run;             // 470
recv_angle   = atan2(recv_rise, recv_run);         // ~5.71 deg
recv_rear_top_z = floor_top_z + mgmt_rise;         // 35
recv_mid_z   = recv_rear_top_z + recv_rise / 2;    // 37.5
hood_rear_x  = bin_front_x - hood_rear_overhang;   // 380
hood_run     = recv_front_x - hood_rear_x;         // 90
hood_rise    = hood_front_clearance_z - hood_rear_clearance_z; // 15
hood_angle   = atan2(hood_rise, hood_run);         // ~9.46 deg
// roof underside height at the cheek midpoint (x = ir_x), xacro hood_side_top_z
hood_side_top_z = hood_rear_clearance_z
    + hood_rise * (ir_x - hood_rear_x) / hood_run; // ~130.8

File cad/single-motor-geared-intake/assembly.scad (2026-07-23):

// Single-motor geared dual-wheel intake concept.
//
// Visual/mechanical concept only. This file does not feed the robot URDF,
// Gazebo model, controller config, or the validated two-motor intake docs.
// Units: mm. Ground frame: +x forward, +y left, +z up.

$fn = 72;

// ---- View toggles ----
show_ball = true;
show_funnel_context = true;
show_drive_arrows = true;
show_labels = false;
show_pitch_circles = true;
explode_gears = 0; // set to 20..60 to lift the gear train for inspection

// ---- Intake geometry copied from the dual-wheel concept scale ----
ball_d = 66;
wheel_r = 60;
wheel_h = 80;
wheel_gap = 56;
nip_x = 540;
wheel_z = 45;
wheel_tilt_deg = 45;
carriage_travel = 8;

wheel_center_y = wheel_gap / 2 + wheel_r;
wheel_left_y = wheel_center_y;
wheel_right_y = -wheel_center_y;

// ---- Single motor + gear train concept ----
gear_z = wheel_z + wheel_h / 2 + 20;
gear_thickness = 8;
gear_module = 2.4;

motor_x = nip_x + 88;
motor_y = 0;
motor_body_d = 37;
motor_body_l = 72;
motor_shaft_d = 6;

pinion_teeth = 18;
output_teeth = 44;
idler_teeth = 22;

pinion_r = gear_pitch_r(pinion_teeth);
output_r = gear_pitch_r(output_teeth);
idler_r = gear_pitch_r(idler_teeth);

left_output = [nip_x, wheel_left_y, gear_z + explode_gears];
right_output = [nip_x, wheel_right_y, gear_z + explode_gears];
pinion_pos = [motor_x, motor_y, gear_z + explode_gears];

pinion_to_idler = pinion_r + idler_r;
idler_to_idler = idler_r + idler_r;
idler_to_output = idler_r + output_r;

// Idler centers are computed from pitch-circle tangencies.
// Left path: pinion -> idler -> left output, so left output rotates the same
// direction as the pinion. Right path: pinion -> idler -> idler -> right
// output, so right output reverses and the wheel inner faces counter-rotate.
left_idler_pos = tangent_idler(pinion_pos, left_output, pinion_to_idler, idler_to_output, -1);
right_idler_a_pos = tangent_idler(
    pinion_pos,
    right_output,
    pinion_to_idler,
    idler_to_idler + idler_to_output,
    1
);
right_idler_b_pos = point_toward(
    right_idler_a_pos,
    right_output,
    idler_to_idler
);

module color_body() { color([0.76, 0.78, 0.78]) children(); }
module color_mount() { color([0.18, 0.19, 0.20]) children(); }
module color_rubber() { color([0.02, 0.025, 0.025]) children(); }
module color_gear() { color([0.86, 0.62, 0.16]) children(); }
module color_motor() { color([0.18, 0.32, 0.58]) children(); }
module color_context() { color([1.0, 0.45, 0.10, 0.30]) children(); }

function gear_pitch_r(teeth) = teeth * gear_module / 2;
function gear_outer_r(teeth) = gear_pitch_r(teeth) + gear_module;
function gear_root_r(teeth) = max(gear_pitch_r(teeth) - 1.25 * gear_module, 3);
function dist_xy(a, b) = sqrt(pow(b[0] - a[0], 2) + pow(b[1] - a[1], 2));
function unit_xy(a, b) =
    let(d = dist_xy(a, b))
    [(b[0] - a[0]) / d, (b[1] - a[1]) / d];
function tangent_idler(a, b, ra, rb, side) =
    let(
        d = dist_xy(a, b),
        u = unit_xy(a, b),
        p = [-u[1], u[0]],
        along = (pow(ra, 2) - pow(rb, 2) + pow(d, 2)) / (2 * d),
        off = sqrt(max(pow(ra, 2) - pow(along, 2), 0)),
        x = a[0] + along * u[0] + side * off * p[0],
        y = a[1] + along * u[1] + side * off * p[1]
    )
    [x, y, gear_z + explode_gears];
function point_toward(a, b, distance) =
    let(u = unit_xy(a, b))
    [a[0] + distance * u[0], a[1] + distance * u[1], gear_z + explode_gears];

module rounded_box(size, r = 3) {
    hull() {
        for (sx = [-1, 1], sy = [-1, 1], sz = [-1, 1])
            translate([
                sx * (size[0] / 2 - r),
                sy * (size[1] / 2 - r),
                sz * (size[2] / 2 - r)
            ])
                sphere(r = r, $fn = 18);
    }
}

module shaft_z(h = 138, d = 8) {
    color([0.45, 0.45, 0.45])
        cylinder(h = h, r = d / 2, center = true);
}

module spur_gear(teeth, thickness = gear_thickness, bore = 8) {
    root_r = gear_root_r(teeth);
    outer_r = gear_outer_r(teeth);
    tooth_w = 360 / teeth * 0.44;

    difference() {
        union() {
            cylinder(h = thickness, r = root_r, center = true, $fn = teeth * 4);
            for (i = [0 : teeth - 1]) {
                rotate([0, 0, i * 360 / teeth])
                    translate([root_r + gear_module * 0.50, 0, 0])
                        rotate([0, 0, 45])
                            cube([gear_module * 1.8, tooth_w * 0.45, thickness], center = true);
            }
            cylinder(h = thickness + 2, r = bore * 1.55, center = true);
        }
        cylinder(h = thickness + 4, r = bore / 2, center = true);
        // Lightening holes.
        for (a = [0 : 60 : 300])
            rotate([0, 0, a])
                translate([root_r * 0.55, 0, 0])
                    cylinder(h = thickness + 5, r = max(root_r * 0.08, 2), center = true, $fn = 24);
    }
}

module pitch_circle(r, thickness = 1.0) {
    color([0.15, 0.55, 1.0, 0.55])
        difference() {
            cylinder(h = thickness, r = r + 0.7, center = true, $fn = 120);
            cylinder(h = thickness + 1, r = r - 0.7, center = true, $fn = 120);
        }
}

module intake_wheel(side = 1) {
    y = side * wheel_center_y;

    // Outward compliance slot and carriage.
    color_mount()
        translate([nip_x, y + side * carriage_travel / 2, wheel_z + wheel_h / 2 + 6])
            cube([70, carriage_travel + 30, 12], center = true);
    color_body()
        translate([nip_x, y, wheel_z + wheel_h / 2 + 6])
            rounded_box([44, 34, 18], 3);

    // Vertical side wheel, tilted as a concept reference to the current bench.
    color_rubber()
        translate([nip_x, y, wheel_z])
            rotate([0, wheel_tilt_deg, 0])
                cylinder(h = wheel_h, r = wheel_r, center = false);

    // Shaft continues up to the gear train.
    translate([nip_x, y, wheel_z + wheel_h / 2])
        shaft_z(h = gear_z - wheel_z + 35, d = 8);

    // Small orange strip to make spin direction visible.
    color([1.0, 0.35, 0.05])
        translate([nip_x + side * 0, y - side * (wheel_r - 5), wheel_z + wheel_h - 12])
            cube([8, 22, 12], center = true);
}

module motor_assembly() {
    // GB37-style gearmotor stood vertically so its output shaft is coaxial
    // with the pinion. A real build could do this with a vertical bracket or
    // replace it with a right-angle gearbox if height becomes a problem.
    body_center_z = gear_z - gear_thickness / 2 - motor_body_l / 2 - 14;

    color_motor()
        translate([motor_x, motor_y, body_center_z])
            cylinder(h = motor_body_l, r = motor_body_d / 2, center = true);
    color([0.08, 0.08, 0.09])
        translate([motor_x, motor_y, gear_z - 11])
            cylinder(h = 30, r = motor_shaft_d / 2, center = true);

    color_mount()
        translate([motor_x, 0, body_center_z - motor_body_l / 2 - 5])
            rounded_box([74, 74, 10], 3);
    color_mount()
        translate([motor_x + 24, 0, body_center_z])
            rounded_box([8, 72, 66], 2);
}

module gear_at(pos, teeth, bore = 8, phase = 0) {
    translate(pos)
        rotate([0, 0, phase]) {
            color_gear()
                spur_gear(teeth, bore = bore);
            if (show_pitch_circles)
                translate([0, 0, gear_thickness / 2 + 1.1])
                    pitch_circle(gear_pitch_r(teeth));
        }
}

module gear_train() {
    // Output gears are coaxial with the intake wheel shafts.
    gear_at(left_output, output_teeth, phase = 4);
    gear_at(right_output, output_teeth, phase = -4);

    // Motor pinion and idlers. The right side has one extra idler to reverse
    // rotation relative to the left output shaft.
    gear_at(pinion_pos, pinion_teeth, bore = motor_shaft_d, phase = 0);
    gear_at(left_idler_pos, idler_teeth, phase = 7);
    gear_at(right_idler_a_pos, idler_teeth, phase = 9);
    gear_at(right_idler_b_pos, idler_teeth, phase = -6);

    // Gear plate above the throat.
    color([0.12, 0.12, 0.12, 0.45])
        translate([nip_x + 38, 0, gear_z - gear_thickness / 2 - 5 + explode_gears])
            cube([210, 270, 4], center = true);

    // Bearing posts under every idler/output shaft make the axes explicit.
    for (p = [left_output, right_output, left_idler_pos, right_idler_a_pos, right_idler_b_pos])
        color_mount()
            translate([p[0], p[1], gear_z - 20 + explode_gears])
                cylinder(h = 30, r = 7, center = true, $fn = 32);
}

module funnel_and_ramp_context() {
    // Front funnel cheeks only as context; not a full robot/chassis.
    color_context() {
        translate([nip_x + 170, 145, 42])
            rotate([0, 0, -13])
                cube([250, 6, 84], center = true);
        translate([nip_x + 170, -145, 42])
            rotate([0, 0, 13])
                cube([250, 6, 84], center = true);

        // Simple center ramp behind the wheels toward the basket/hopper.
        translate([nip_x - 75, 0, 18])
            rotate([0, -8, 0])
                cube([190, 170, 8], center = true);
    }
}
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

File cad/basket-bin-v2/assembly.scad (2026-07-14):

// Basket bin v2.1 + entry hood assembly.
//
//   openscad assembly.scad                      # full assembly
//   openscad -D 'explode=80' assembly.scad      # bin lifted out
//   openscad -D 'show_context=false' ...        # weldments only
//
// Frames: mm, ground frame, +x forward (see params.scad).
include <params.scad>
use <bin.scad>
use <hood.scad>
use <chassis_context.scad>

show_bin     = true;
show_hood    = true;
show_context = true;
show_balls   = true;
explode      = 0;   // mm to lift the bin for the removal check

if (show_context) chassis_context(with_balls = show_balls && explode == 0);
if (show_bin) translate([0, 0, explode]) bin();
if (show_hood) hood();

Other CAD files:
cad/basket-bin-v2/bin.scad
cad/basket-bin-v2/chassis_context.scad
cad/basket-bin-v2/hood.scad
cad/basket-bin-v2/lib.scad
cad/basket-bin-v2/print-segments.scad
worlds/Tennis Court with Fence.skp

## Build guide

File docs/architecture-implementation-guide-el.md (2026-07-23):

# Tennis Robot Architecture Implementation Guide

Αυτό είναι το βασικό architecture guide για την επόμενη φάση υλοποίησης.
Από εδώ και πέρα, η υλοποίηση πρέπει να ξεκινά από τα active baseline
documents και όχι από την τρέχουσα μορφή του Webots controller.

## 1. Architecture Reset Decision

Ο υπάρχων κώδικας θεωρείται **legacy reference**.

Αυτό σημαίνει:

- δεν είναι πλέον η πηγή αλήθειας για τη νέα αρχιτεκτονική,
- μπορεί να χρησιμοποιηθεί για χρήσιμα κομμάτια, patterns, smoke tests και telemetry ideas,
- δεν πρέπει να περιορίζει τον νέο σχεδιασμό,
- μπορεί να αντικατασταθεί σταδιακά ή πλήρως όταν συγκρούεται με τα νέα baseline docs.

Η νέα πηγή αλήθειας είναι τα active baseline documents:

- `docs/validation-plan-el.md`
- `docs/court-knowledge-model-specification.md`
- `docs/archive/collection-state-machine-plan-el.md` (ιστορικό, μη ενεργό)
- `docs/mission-dashboard-plan-el.md`
- `docs/concept-a-funnel-lift-wheel-plan.md`
- `docs/prototype-purchase-list-el.md`
- `docs/plywood-cut-list.md`

## 2. Implementation Principle

Κάθε νέα υλοποίηση πρέπει να απαντά πρώτα:

```text
Ποιο active baseline requirement υλοποιεί;
Ποιο sensor contract χρησιμοποιεί;
Ποιο state machine state επηρεάζει;
Ποιο telemetry/dashboard field ενημερώνει;
Ποιο validation DoD βοηθάει να αποδειχθεί;
```

Αν μια αλλαγή δεν μπορεί να συνδεθεί με κάποιο από αυτά, πρέπει να θεωρείται
πειραματική και όχι baseline implementation.

## 3. Webots Rebuild Direction

Η επόμενη Webots φάση πρέπει να ανακατασκευάσει το robot ώστε να καλύπτει τη
γενική σχεδίαση αντί να συντηρεί το παλιό minimal demo.

### Required Webots Robot Shape

Το simulated robot πρέπει να περιλαμβάνει:

- differential-drive mobile base,
- front collector placeholder με wide intake/funnel geometry,
- simulated intake zone,
- low 360-degree LiDAR στα 25-35 cm,
- OAK-D approximation στα 40-60 cm με ελαφριά κλίση προς τα κάτω,
- front low collection sensors ή simulated collection trigger,
- clear coordinate frames για base, camera, LiDAR και collector center,
- telemetry output που μπορεί να τροφοδοτήσει το Mission Dashboard.

### Required Webots Environment

Το court πρέπει να υποστηρίζει:

- full ή half-court Court Knowledge Model creation και selected-side scan,
- Court Knowledge Model-gated court matrix,
- selectable collection side,
- tennis balls σε realistic και edge-case θέσεις,
- static obstacles,
- moving human/person obstacles,
- blocked paths,
- balls κοντά σε γραμμές, δίχτυ, γωνίες και σκιά όπου είναι εφικτό.

## 4. Target Runtime Architecture

Η νέα υλοποίηση πρέπει να χωρίζεται σε layers:

```text
Sensors
  ↓
Perception
  ↓
World / Court Model
  ↓
Court Knowledge Model / Side Scan
  ↓
Collection Planning
  ↓
Target Selection
  ↓
Collection State Machine
  ↓
Safety / Recovery
  ↓
Actuation
  ↓
Telemetry / Mission Dashboard
```

### Layer Responsibilities

| Layer | Responsibility |
| --- | --- |
| Sensors | Raw camera, depth, LiDAR, odometry, front collection sensors. |
| Perception | Ball/person observations, confidence, bearing, distance. |
| World / Court Model | Court Knowledge Model, matrix cells, coverage, obstacle map, ball map, target states. |
| Court Knowledge Model / Side Scan | Require a valid Court Knowledge Model, scan the selected collection side, and update matrix cells. |
| Collection Planning | Build an ordered collection plan from matrix data, current pose, obstacles and target confidence. |
| Target Selection | Choose the next planned target using distance, confidence, stale data and obstacle cost. |
| Collection State Machine | Approach, fine alignment, attempt, verification, retry. |
| Safety / Recovery | Human stop, blocked path, stuck robot, lost ball, full bucket, jam. |
| Actuation | Drive commands and collector commands. |
| Telemetry / Dashboard | Mission progress, timeline, safety, performance and report fields. |

## 5. Sensor Contracts

### LiDAR

```text
LiDAR = navigation, safety, obstacle map
```

LiDAR outputs:

```text
obstacle_sectors
blocked_paths
safe_heading_deg
occupancy_or_cost_map
human_or_obstacle_events
```

Δεν χρησιμοποιείται ως κύριο sensor για ball recognition.

### OAK-D / Camera

```text
OAK-D = ball/person recognition
```

OAK-D outputs:

```text
balls_visible
people_visible
ball_observations[]τ
target_confidence
ball_bearing_rad
ball_distance_m
ball_world_xy
```

### Front Collection Sensors

```text
Low front sensors = final collection confirmation
```

Collection sensor outputs:

```text
ball_present
ball_crossed_entry
stored_ball_count
collection_confirmed
jam_or_partial_capture
```

## 6. Core State Machines

### Court Knowledge Model-Gated Collection Planning

Το collection planning behavior ακολουθεί:

```text
NO_COURT_KNOWLEDGE_MODEL
↓
BUILDING_COURT_KNOWLEDGE_MODEL
↓
COURT_KNOWLEDGE_MODEL_READY
↓
SIDE_SCAN
↓
PLAN_COLLECTION
↓
EXECUTE_COLLECTION_PLAN
```

Source: `docs/court-knowledge-model-specification.md`

### Collection

Το collection behavior ακολουθεί:

```text
BALL_DETECTED
↓
TARGET_SELECTED
↓
APPROACH_TARGET
↓
FINE_ALIGNMENT
↓
COLLECTION_ATTEMPT
↓
VERIFY_COLLECTION
↓
SUCCESS
↓
RESUME_SEARCH
```

Historical source: `docs/archive/collection-state-machine-plan-el.md`.
For the active `collect_route` behavior use `docs/collection-route-rules-el.md`.

### Mission Dashboard

Κάθε state transition πρέπει να ενημερώνει:

```text
mission progress
current zone
current action
current target
timeline events
performance counters
safety counters
```

Source: `docs/mission-dashboard-plan-el.md`

## 7. First Implementation Scope

Η πρώτη νέα υλοποίηση πρέπει να είναι μικρή αλλά πλήρης σαν vertical slice:

1. Rebuild/clean Webots robot model with target sensor layout.
2. Implement or adapt perception outputs into stable observation contracts.
3. Add Court Knowledge Model storage and require a valid model before collection.
4. Add matrix cell model for the selected court.
5. Add selected-side scan that updates matrix cells with ball observations and blocked cells.
6. Add ordered collection plan generation from matrix data.
7. Add target selection from planned targets.
8. Add collection state machine with approach, fine alignment, attempt and verification.
9. Add retry with `max_retries = 3`.
10. Add mission dashboard fields and timeline events.
11. Add smoke/regression scenario for a Court Knowledge Model -> side scan -> planned collection mission.

## 8. Migration Rule

When touching existing code:

- keep useful code only if it supports the new contracts,
- prefer extracting reusable pieces over extending legacy state tangles,
- do not preserve old names or states just because they exist,
- document any temporary compatibility layer,
- remove compatibility once the new state machine is stable.

Examples of legacy concepts that may be reused but should not define the new design:

- old `idle -> scan -> align -> approach -> capture -> collected` collector flow,
- old dashboard KPIs centered on requested/actual mode,
- route visualization presets that do not know Court Knowledge Model status, matrix cells or mission progress,
- simulated collection without verification semantics.

## 9. Telemetry Contract

Every implementation step should update at least one telemetry group:

```text
mission.*
scan.*
court_knowledge.*
matrix.*
target.*
collection.*
perception.*
navigation.*
safety.*
performance.*
```

Minimum fields for the first dashboard:

```text
mission_name
mission_elapsed_s
current_action
current_cell
court_knowledge_status
court_knowledge_model_id
collection_side
matrix_coverage_pct
current_target_id
coverage_pct
balls_detected
balls_collected
collection_attempts
collection_retries
human_encounters
obstacle_avoidance_events
timeline_events[]
```

## 10. Validation Rule

No implementation phase is considered complete unless it produces evidence for
the validation plan:

- repeatable Webots scenario,
- telemetry or dashboard output,
- pass/fail behavior for the relevant DoD,
- documented limitation if Webots cannot prove the behavior.

Source: `docs/validation-plan-el.md`

## 11. Recovery Plan Placeholder

Μετά το πρώτο vertical slice, χρειάζεται ξεχωριστό Recovery Plan για:

- lost ball,
- stuck robot,
- blocked path,
- full bucket,
- jammed collector,
- stale target,
- unsafe human proximity.

Μέχρι να γραφτεί αυτό το plan, οι υλοποιήσεις πρέπει να κρατούν recovery hooks
και telemetry events, αλλά να μην προσπαθούν να λύσουν όλες τις περιπτώσεις μαζί.

## 12. Definition Of Ready For New Work

Πριν ξεκινήσει νέα υλοποίηση, πρέπει να είναι σαφές:

1. Ποιο baseline document αφορά.
2. Ποιο state machine αλλάζει.
3. Ποια telemetry fields θα γράφει.
4. Ποιο Webots scenario θα το αποδεικνύει.
5. Ποιο legacy behavior μπορεί να αντικατασταθεί.

Αυτός είναι ο κανόνας για να μη γυρίσει το project σε ad-hoc simulation demo.

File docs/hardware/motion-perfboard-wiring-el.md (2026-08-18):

# Motion Perfboard Wiring Reference

Αυτό το έγγραφο περιγράφει την πλακέτα perfboard για το πρώτο 4WD motion
prototype του tennis robot.

Στόχος: να φτιαχτεί μια καθαρή logic/distribution πλακέτα για:

- Arduino Mega 2560 Rev3 ως motion MCU
- 2x BTS7960 / IBT-2 motor drivers, ένας ανά πλευρά
- 4x DC geared motors με encoder, δύο μοτέρ παράλληλα ανά πλευρά
- encoder headers για odometry/diagnostics
- MPU6050 IMU για yaw-rate/acceleration diagnostics μέσω I2C
- κοινό logic ground, 5V encoder rail και καθαρά control signals

## 0. Τι Είναι Πρακτικά Η Πλακέτα

Η σωστή ιδέα είναι **carrier / breakout perfboard**, όχι power board. Το Mega
μένει αφαιρούμενο και η πλακέτα προσφέρει υποδοχές για drivers, encoders, IMU και
κουμπιά.

Με την υπάρχουσα perfboard 80x120 mm προτείνεται:

- το Mega να στερεωθεί με M3 αποστάτες πάνω από την πλακέτα ή δίπλα της,
- το J1 να συνδεθεί στα Mega pins με κοντό, αριθμημένο harness,
- να μη συγκολληθεί το Mega απευθείας στην perfboard,
- να μείνει προσβάσιμο το USB και το reset,
- να υπάρχουν θηλυκά headers/βύσματα ώστε drivers και αισθητήρες να αλλάζουν.

Τα headers του Mega δεν σχηματίζουν απλό ορθογώνιο πλέγμα perfboard. Για να
κουμπώνει σαν Arduino shield χρειάζονται σωστά τοποθετημένα long male/stackable
headers και ακριβές template. Για το πρώτο prototype το ξεχωριστό J1 harness
είναι πιο εύκολο στην κατασκευή και επισκευή.

## Διαγράμματα

Επισκόπηση συστήματος (power domain εκτός perfboard vs logic domain):

Motion control wiring

Pinout των headers J1-J9 — πώς ενώνεται κάθε component στην perfboard:

Motion perfboard header pinout

## 1. Σημαντικό Όριο Της Perfboard

Η perfboard **δεν μεταφέρει ρεύμα μοτέρ**.

Πάνω στην perfboard περνάνε μόνο:

```text
Arduino Mega control signals
BTS7960 logic pins
encoder signals
5V encoder supply
common GND reference
```

Το 12V high-current κομμάτι περνάει εκτός perfboard:

```text
Battery +
  -> main motor fuse
  -> automotive relay contact 30
relay contact 87
  -> power distribution / terminal block
  -> BTS7960 B+ terminals

Battery -
  -> power distribution / terminal block
  -> BTS7960 B- terminals
  -> Arduino/perfboard GND reference
```

Μη βάλεις ποτέ τα ρεύματα μοτέρ μέσα από λεπτές perfboard διαδρομές.

## 2. Safety Chain: Fuse, Start, E-Stop

Η πρώτη κίνηση του robot πρέπει να έχει φυσική ασφάλεια, όχι μόνο software stop.

### High-current motor power chain με το υπάρχον E-stop 10A

```text
Battery +
  -> main motor fuse, 20A αρχικά
  -> automotive relay contact 30
automotive relay contact 87 (όχι 87a)
  -> distribution block
  -> Left BTS7960 B+
  -> Right BTS7960 B+

Battery -
  -> distribution block
  -> Left BTS7960 B-
  -> Right BTS7960 B-
```

Το E-stop `39-00013660` είναι 10A, ενώ η motor fuse είναι 20A. Άρα **δεν**
περνάμε το ρεύμα των μοτέρ από το E-stop. Το NC contact του οδηγεί μόνο το πηνίο
ενός relay αυτοκινήτου 12V/40A:

```text
Electronics fused +12V
  -> main toggle switch
  -> E-stop NC contact
  -> relay coil 86
relay coil 85
  -> Battery GND
```

Έτσι, πάτημα E-stop ανοίγει το NC, πέφτει το relay και το contact 30-87 κόβει
φυσικά το +12V προς τα δύο `B+`. Αν η βάση του relay έχει ενσωματωμένη δίοδο,
τηρείται υποχρεωτικά η πολικότητα 86=+12V και 85=GND. Μην χρησιμοποιήσεις το
87a. Προαιρετικά βάλε flyback diode παράλληλα στο πηνίο (κάθοδος στο 86,
άνοδος στο 85) αν δεν υπάρχει ήδη.

Προτεινόμενες αρχικές ασφάλειες:

| Fuse | Προτεινόμενη τιμή | Κόβει | Σημείωση |
|---|---:|---|---|
| Main motor fuse | 20A αρχικά, 25A μόνο αν χρειαστεί | Drive motor branch | Να είναι κοντά στη μπαταρία |
| Electronics fuse | 3A-5A | Arduino/SBC/sensors branch | Ξεχωριστή από τα μοτέρ |
| Accessory 12V fuse | 5A-10A | Buck-boost/accessories | Μόνο αν υπάρχει accessory rail |

Η τιμή της main fuse θα οριστικοποιηθεί μετά από μέτρηση ρεύματος. Ξεκινάμε
συντηρητικά, γιατί στο πρώτο prototype θέλουμε να βρούμε λάθη καλωδίωσης πριν
γίνουν ακριβά.

### Emergency stop

Το emergency stop πρέπει να κόβει **φυσικά** την τροφοδοσία των motor drivers.

```text
E-stop pressed
  -> no +12V at BTS7960 B+
  -> motors cannot move even if Arduino/PWM fails
```

Προτίμηση:

- normally-closed contact,
- latching mushroom button,
- rated για DC current πάνω από την επιλεγμένη ασφάλεια ή να οδηγεί relay/contactor
  που έχει το κατάλληλο DC rating.

Μην βασιστείς μόνο σε κουμπί που πάει σε Arduino input για emergency stop.
Μπορούμε να το διαβάζουμε και από το Arduino για status, αλλά η πραγματική
ασφάλεια πρέπει να κόβει το power path.

### Start / Arm button

Το start button δεν είναι emergency stop. Είναι logic input προς το Arduino Mega
για να οπλίζει την κίνηση μετά από reset ή μετά από E-stop release.

Προτεινόμενη λογική:

```text
Power on
  -> Arduino boots DISARMED
  -> BTS7960 enables LOW
  -> user presses START/ARM
  -> Arduino checks that E-stop status is clear
  -> Arduino enables BTS7960
  -> motors remain stopped until a fresh host command arrives

E-stop pressed
  -> Arduino disables BTS7960
  -> motor power is also cut by E-stop chain

Command timeout
  -> Arduino writes zero PWM immediately
  -> driver remains armed, but a fresh command is required for motion
```

Προτεινόμενο start button wiring:

| Start button | Arduino Mega | Σκοπός |
|---|---|---|
| One side | D32 | `START_ARM` input |
| Other side | `LOGIC_GND` | Active-low button |

Στο firmware:

```cpp
pinMode(32, INPUT_PULLUP);
```

Με αυτό:

```text
HIGH = not pressed
LOW  = pressed
```

Το firmware κάνει debounce και οπλίζει μόνο από `DISARMED`. Το κουμπί δεν
ξεκινά κίνηση μόνο του και δεν αντικαθιστά το USB serial heartbeat.

### Optional E-stop status input

Χρησιμοποίησε το δεύτερο, NO contact του 1NO+1NC E-stop για status:

| E-stop auxiliary contact | Arduino Mega | Σκοπός |
|---|---|---|
| One side | D33 | `ESTOP_STATUS` input |
| Other side | `LOGIC_GND` | Active-low status |

Αυτό είναι μόνο telemetry/status. Δεν αντικαθιστά το φυσικό κόψιμο του 12V motor
power.

Σε αυτό το wiring το NO κλείνει όταν πατηθεί το E-stop, άρα το D33 γίνεται LOW
και σημαίνει `TRIPPED`. Πριν κολλήσεις, επιβεβαίωσε με continuity tester ποιο
ζεύγος είναι NC και ποιο NO, γιατί οι αριθμοί ακροδεκτών διαφέρουν ανά μοντέλο.

## 3. System Topology

```text
Arduino Mega 2560
    |
    | PWM / enable signals
    v
Motion perfboard
    |
    +--> Left BTS7960  -> left front motor + left rear motor
    |
    +--> Right BTS7960 -> right front motor + right rear motor
    |
    +<-- 4x encoder A/B signals
```

Για το πρώτο prototype, κάθε BTS7960 οδηγεί δύο μοτέρ παράλληλα στην ίδια πλευρά.
Αν δούμε υπερβολικό ρεύμα, ζέσταμα ή άνισο τράβηγμα, προσθέτουμε άλλα 2 BTS7960
ώστε να πάμε σε ένα driver ανά μοτέρ.

### Wiring Diagram

```mermaid
flowchart LR
    BAT["12V Battery"]
    FUSE["Main Motor Fuse<br/>20A initial"]
    ESTOP["Emergency Stop<br/>NC latching"]
    MSW["Main Switch"]
    DIST["12V/GND Distribution<br/>terminal block"]
    LDRV["Left BTS7960<br/>driver"]
    RDRV["Right BTS7960<br/>driver"]
    LFM["Left Front<br/>Motor"]
    LRM["Left Rear<br/>Motor"]
    RFM["Right Front<br/>Motor"]
    RRM["Right Rear<br/>Motor"]

    MEGA["Arduino Mega<br/>Motion MCU"]
    PERF["Motion Perfboard<br/>logic + encoder headers"]
    START["Start / Arm<br/>button"]
    AUX["Optional E-stop<br/>status contact"]
    IMU["MPU6050 IMU<br/>I2C"]
    LFENC["LF Encoder"]
    LRENC["LR Encoder"]
    RFENC["RF Encoder"]
    RRENC["RR Encoder"]

    BAT --> FUSE --> ESTOP --> MSW --> DIST
    DIST --> LDRV
    DIST --> RDRV
    LDRV --> LFM
    LDRV --> LRM
    RDRV --> RFM
    RDRV --> RRM

    MEGA <-->|"5V, GND, PWM, EN, encoder signals"| PERF
    PERF -->|"RPWM, LPWM, EN"| LDRV
    PERF -->|"RPWM, LPWM, EN"| RDRV
    START --> PERF
    AUX --> PERF
    IMU -->|"SDA, SCL, 5V, GND"| PERF
    LFENC --> PERF
    LRENC --> PERF
    RFENC --> PERF
    RRENC --> PERF
```

Στο διάγραμμα, η επάνω διαδρομή είναι το high-current motor power. Η κάτω
διαδρομή είναι logic/control/encoder και περνάει από την perfboard.

## 4. Arduino Mega Pin Map

### BTS7960 Control Pins

| Arduino Mega | Perfboard net | BTS7960 pin | Σκοπός |
|---|---|---|---|
| D5 PWM | `LEFT_RPWM` | Left driver `RPWM` | Αριστερή πλευρά, φορά A |
| D6 PWM | `LEFT_LPWM` | Left driver `LPWM` | Αριστερή πλευρά, φορά B |
| D30 | `LEFT_EN` | Left driver `R_EN` + `L_EN` | Enable αριστερού driver |
| D9 PWM | `RIGHT_RPWM` | Right driver `RPWM` | Δεξιά πλευρά, φορά A |
| D10 PWM | `RIGHT_LPWM` | Right driver `LPWM` | Δεξιά πλευρά, φορά B |
| D31 | `RIGHT_EN` | Right driver `R_EN` + `L_EN` | Enable δεξιού driver |
| 5V | `LOGIC_5V` | Both drivers `VCC` | Logic τροφοδοσία |
| GND | `LOGIC_GND` | Both drivers `GND` | Κοινή γείωση |

Σημείωση: στα περισσότερα BTS7960 modules τα `R_EN` και `L_EN` μπορούν να
δεθούν μαζί και να οδηγούνται από ένα enable pin ανά driver. Αν το συγκεκριμένο
module απαιτήσει ξεχωριστό έλεγχο, κρατάμε χώρο στην perfboard για να τα
χωρίσουμε αργότερα.

### Encoder Pins

| Motor | Encoder A | Encoder B | Encoder VCC | Encoder GND |
|---|---|---|---|---|
| Left front | D2 interrupt | D22 | `ENC_5V` | `LOGIC_GND` |
| Left rear | D3 interrupt | D23 | `ENC_5V` | `LOGIC_GND` |
| Right front | D18 interrupt | D24 | `ENC_5V` | `LOGIC_GND` |
| Right rear | D19 interrupt | D25 | `ENC_5V` | `LOGIC_GND` |

### Safety / User Inputs

| Arduino Mega | Net | Χρήση |
|---|---|---|
| D32 | `START_ARM` | Start/arm button, active-low with `INPUT_PULLUP` |
| D33 | `ESTOP_STATUS` | Optional E-stop auxiliary status, active-low with `INPUT_PULLUP` |
| D34 | `ARMED_LED` | LED ένδειξης armed, output μέσω αντίστασης 470Ω |

### MPU6050 IMU / I2C

| Arduino Mega | Net | MPU6050 pin | Χρήση |
|---|---|---|---|
| D20 / SDA | `I2C_SDA` | `SDA` | I2C data |
| D21 / SCL | `I2C_SCL` | `SCL` | I2C clock |
| 5V or 3.3V | `IMU_VCC` | `VCC` | Τροφοδοσία module |
| GND | `LOGIC_GND` | `GND` | Κοινή γείωση |

Τα περισσότερα MPU6050 breakout modules δέχονται 5V επειδή έχουν regulator,
αλλά αυτό πρέπει να επιβεβαιωθεί στο συγκεκριμένο module. Αν το module γράφει
μόνο 3.3V, χρησιμοποίησε 3.3V και έλεγξε αν χρειάζεται level shifting στο I2C.

Στο prototype το MPU6050 χρησιμοποιείται για yaw-rate/acceleration sanity checks
και βελτίωση odometry diagnostics. Δεν το αντιμετωπίζουμε ως απόλυτη πυξίδα.

Για αρχικό bring-up μετράμε interrupt στο `A` και διαβάζουμε το `B` για φορά.
Αργότερα, αν θέλουμε πλήρες quadrature decoding και στα 8 edges, μπορούμε να
περάσουμε σε Teensy/ESP32 ή σε pin-change interrupt library.

## 5. Perfboard Headers

### Header J1 - Arduino Mega Control

| Pin | Net | Προς |
|---:|---|---|
| 1 | `LEFT_RPWM` | Mega D5 |
| 2 | `LEFT_LPWM` | Mega D6 |
| 3 | `RIGHT_RPWM` | Mega D9 |
| 4 | `RIGHT_LPWM` | Mega D10 |
| 5 | `LEFT_EN` | Mega D30 |
| 6 | `RIGHT_EN` | Mega D31 |
| 7 | `START_ARM` | Mega D32 |
| 8 | `ESTOP_STATUS` | Mega D33, optional |
| 9 | `ARMED_LED` | Mega D34 |
| 10 | `I2C_SDA` | Mega D20 / SDA |
| 11 | `I2C_SCL` | Mega D21 / SCL |
| 12 | `LOGIC_5V` | Mega 5V |
| 13 | `LOGIC_GND` | Mega GND |

### Header J2 - Left BTS7960 Logic

| Pin | Net | BTS7960 pin |
|---:|---|---|
| 1 | `LEFT_RPWM` | `RPWM` |
| 2 | `LEFT_LPWM` | `LPWM` |
| 3 | `LEFT_EN` | `R_EN` |
| 4 | `LEFT_EN` | `L_EN` |
| 5 | `LOGIC_5V` | `VCC` |
| 6 | `LOGIC_GND` | `GND` |

### Header J3 - Right BTS7960 Logic

| Pin | Net | BTS7960 pin |
|---:|---|---|
| 1 | `RIGHT_RPWM` | `RPWM` |
| 2 | `RIGHT_LPWM` | `LPWM` |
| 3 | `RIGHT_EN` | `R_EN` |
| 4 | `RIGHT_EN` | `L_EN` |
| 5 | `LOGIC_5V` | `VCC` |
| 6 | `LOGIC_GND` | `GND` |

### Headers J4-J7 - Motor Encoders

Χρησιμοποίησε 4-pin headers, ένα ανά motor encoder:

| Header | Motor | Pin 1 | Pin 2 | Pin 3 | Pin 4 |
|---|---|---|---|---|---|
| J4 | Left front encoder | `ENC_5V` | `LOGIC_GND` | D2 / `LF_ENC_A` | D22 / `LF_ENC_B` |
| J5 | Left rear encoder | `ENC_5V` | `LOGIC_GND` | D3 / `LR_ENC_A` | D23 / `LR_ENC_B` |
| J6 | Right front encoder | `ENC_5V` | `LOGIC_GND` | D18 / `RF_ENC_A` | D24 / `RF_ENC_B` |
| J7 | Right rear encoder | `ENC_5V` | `LOGIC_GND` | D19 / `RR_ENC_A` | D25 / `RR_ENC_B` |

Τα χρώματα καλωδίων των encoders να επιβεβαιωθούν από το datasheet/label του
μοτέρ πριν κολληθούν. Μην υποθέσεις ότι είναι ίδια με άλλο motor model.

### Header J8 - User Controls

| Pin | Net | Σύνδεση |
|---:|---|---|
| 1 | `START_ARM` | Start/arm button side A |
| 2 | `LOGIC_GND` | Start/arm button side B |
| 3 | `ESTOP_STATUS` | Optional E-stop auxiliary side A |
| 4 | `LOGIC_GND` | Optional E-stop auxiliary side B |
| 5 | `ARMED_LED` | Άνοδος LED μέσω αντίστασης 470Ω |
| 6 | `LOGIC_GND` | Κάθοδος LED |

Αν το φωτιζόμενο κουμπί έχει ενσωματωμένη αντίσταση για **12V**, μην οδηγήσεις
το LED του απευθείας από D34· χρησιμοποίησε ξεχωριστό 5V LED ή transistor driver
σύμφωνα με το datasheet του κουμπιού.

### Header J9 - MPU6050 IMU

| Pin | Net | MPU6050 pin |
|---:|---|---|
| 1 | `IMU_VCC` | `VCC` |
| 2 | `LOGIC_GND` | `GND` |
| 3 | `I2C_SDA` | `SDA` |
| 4 | `I2C_SCL` | `SCL` |

Το `XDA`, `XCL`, `AD0` και `INT` του MPU6050 μένουν ασύνδετα στο πρώτο bring-up,
εκτός αν η βιβλιοθήκη/firmware που θα χρησιμοποιήσουμε ζητήσει interrupt pin.

## 6. Motor Power Wiring

Η ισχύς δεν περνάει από την perfboard.

### Left Side Motors

| Left BTS7960 terminal | Σύνδεση |
|---|---|
| `B+` | +12V από distribution block, μετά από fuse και relay contact 87 |
| `B-` | Battery GND / power ground |
| `M+` | Left front motor lead A + left rear motor lead A |
| `M-` | Left front motor lead B + left rear motor lead B |

### Right Side Motors

| Right BTS7960 terminal | Σύνδεση |
|---|---|
| `B+` | +12V από distribution block, μετά από fuse και relay contact 87 |
| `B-` | Battery GND / power ground |
| `M+` | Right front motor lead A + right rear motor lead A |
| `M-` | Right front motor lead B + right rear motor lead B |

Αν μία πλευρά γυρίζει ανάποδα, διόρθωσε πρώτα στο software. Αν χρειαστεί,
αντάλλαξε `M+`/`M-` στη συγκεκριμένη πλευρά. Μην αλλάξεις τα encoder wires για
να διορθώσεις φορά μοτέρ.

## 7. Grounding Plan

Όλα πρέπει να έχουν κοινή αναφορά γείωσης:

```text
Battery GND
  -> BTS7960 B-
  -> BTS7960 logic GND
  -> perfboard LOGIC_GND
  -> Arduino Mega GND
  -> encoder GND
```

Χωρίς κοινό ground, τα PWM και encoder signals μπορεί να φαίνονται τυχαία ή να
μην λειτουργούν καθόλου.

## 8. 5V Plan

Για το πρώτο prototype:

```text
Arduino Mega 5V -> perfboard LOGIC_5V / ENC_5V
```

Αυτό τροφοδοτεί:

- BTS7960 logic `VCC`
- encoder `VCC`

Μη χρησιμοποιήσεις το 5V rail για μοτέρ, relay coils ή άλλα φορτία. Αν αργότερα
μπουν πολλοί αισθητήρες, βάλε ξεχωριστό 5V buck converter και κράτα κοινό GND.

## 9. Recommended Perfboard Layout

Πρακτική διάταξη:

```text
[J1 harness προς Mega]        [J2 Left BTS7960 logic]   [J3 Right BTS7960 logic]

[J4 LF encoder] [J5 LR encoder] [J6 RF encoder] [J7 RR encoder]

[J8 controls/LED]             [J9 MPU6050]

5V rail along top
GND rail along bottom
Signal wires short and labelled
```

### Σειρά κατασκευής

1. Βάλε προσωρινά όλα τα headers και το Mega για να ελέγξεις χώρο, USB και reset.
2. Σημάδεψε Pin 1 σε J1-J9 και γράψε `5V`, `GND`, `A`, `B`, `RPWM`, `LPWM` πάνω
   και κάτω από την πλακέτα.
3. Κόλλησε πρώτα μόνο τις δύο logic μπάρες 5V/GND. Δεν συνδέονται ποτέ με +12V.
4. Κόλλησε J1, J2, J3 και έλεγξε κάθε σύνδεση με continuity tester.
5. Κόλλησε J4-J7, μετά J8/J9, ελέγχοντας ότι δεν υπάρχει short 5V-GND.
6. Πρόσθεσε 100nF κεραμικό κοντά σε κάθε encoder header μεταξύ 5V-GND και
   100-470µF electrolytic στην είσοδο της logic rail, με σωστή πολικότητα.
7. Στερέωσε τα καλώδια με strain relief. Τα encoder A/B να περνούν μακριά από
   τα M+/M- και, όπου γίνεται, συνεστραμμένα με GND.
8. Σύνδεσε το J1 harness pin-προς-pin και κάνε δεύτερο continuity check πριν
   μπει USB ή μπαταρία.

Μην τροφοδοτείς ταυτόχρονα το Mega από USB και από εξωτερικό 5V στο pin `5V`.
Στο πρώτο bring-up τροφοδότησέ το μόνο από USB· το 5V του Mega τροφοδοτεί τη
μικρή logic rail (BTS7960 logic + encoders), όχι Pi, relay ή μοτέρ.

Πρότεινε χρώματα:

| Χρώμα | Χρήση |
|---|---|
| Κόκκινο | `LOGIC_5V` / `ENC_5V` |
| Μαύρο | `LOGIC_GND` |
| Κίτρινο | PWM signals |
| Πορτοκαλί | Enable signals |
| Μπλε/Πράσινο | Encoder A/B |
| Λευκό | Start/E-stop status inputs |
| Μωβ | I2C SDA/SCL προς MPU6050 |

## 10. First Power-On Checklist

Πριν συνδέσεις τα μοτέρ στους drivers:

1. Μέτρα `LOGIC_5V` προς `LOGIC_GND`: πρέπει να είναι περίπου 5V.
2. Μέτρα συνέχεια `Arduino GND` προς `BTS7960 logic GND`: πρέπει να είναι σχεδόν 0 ohm.
3. Επιβεβαίωσε ότι δεν υπάρχει 12V πάνω στην perfboard.
4. Επιβεβαίωσε ότι κάθε encoder παίρνει 5V και GND στη σωστή πολικότητα.
5. Επιβεβαίωσε ότι το MPU6050 VCC ταιριάζει με το module: 5V tolerant ή 3.3V only.
6. Χωρίς Mega συνδεδεμένο, επιβεβαίωσε ότι το E-stop ρίχνει το relay και κόβει
   το +12V και στα δύο BTS7960 `B+`.
7. Επιβεβαίωσε ότι το main fuse είναι κοντά στη μπαταρία.
8. Επιβεβαίωσε ότι START είναι `HIGH` idle/`LOW` pressed και ESTOP_STATUS είναι
   `HIGH` released/`LOW` pressed.
9. Σήκωσε `LEFT_EN` / `RIGHT_EN` μόνο από software, όχι με μόνιμο jumper στο 5V.
10. Δοκίμασε πρώτα encoder hand test, γυρίζοντας κάθε τροχό με το χέρι.
11. Δοκίμασε MPU6050 I2C scan και stationary gyro bias check.
12. Δοκίμασε κάθε πλευρά με χαμηλό PWM χωρίς βάρος στο robot.
13. Μετά από 10-20 δευτερόλεπτα, έλεγξε θερμοκρασία BTS7960 και καλωδίων.

## 11. First Motion Test Limits

Για τις πρώτες δοκιμές:

```text
PWM limit: 40-80 / 255
test duration: 2-5 seconds
robot lifted or wheels off ground first
then very slow floor test
```

Σταμάτα αμέσως αν:

- ζεσταίνεται γρήγορα driver ή καλώδιο,
- μυρίζει πλαστικό/μονωτικό,
- κάποια πλευρά τραβάει πολύ πιο δυνατά,
- οι encoder counts πάνε ανάποδα ή μηδενίζουν,
- πέφτει/κάνει reset το Arduino Mega.

## 12. Upgrade Path Σε 4 Drivers

Αν χρειαστούν 4 BTS7960, κρατάμε την ίδια λογική αλλά χωρίζουμε τα motor outputs:

```text
Left front BTS7960  -> left front motor
Left rear BTS7960   -> left rear motor
Right front BTS7960 -> right front motor
Right rear BTS7960  -> right rear motor
```

Η perfboard μπορεί να επεκταθεί με δύο επιπλέον BTS7960 logic headers. Τα encoder
headers δεν αλλάζουν.

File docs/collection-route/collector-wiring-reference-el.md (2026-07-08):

# Collector Wiring Reference

Αυτό το έγγραφο είναι ο πίνακας αναφοράς για το πρώτο λειτουργικό prototype του
collector, με:

- Arduino Nano
- TB6612FNG motor driver
- GB37Y3530 12V DC gear motor με encoder
- 2x Adafruit IR break beam sensors
- εξωτερικό 12V τροφοδοτικό για το μοτέρ

Στόχος του πρώτου wiring είναι να γυρίσει ελεγχόμενα ο intake roller, να
διαβάζουμε encoder pulses, και να ανιχνεύουμε μπαλάκι στην είσοδο και στην έξοδο
του collector.

## Γρήγορη Διάγνωση

Αν βλέπεις PWM/serial messages αλλά ο κινητήρας δεν γυρίζει, το πιο πιθανό είναι
ότι λείπει η τροφοδοσία μοτέρ:

```text
12V PSU -> TB6612 VM
12V PSU GND -> TB6612 GND
```

Το `VCC` του TB6612 τροφοδοτεί μόνο τη λογική. Το μοτέρ παίρνει ισχύ από το `VM`.

## 1. Arduino Nano προς TB6612FNG

| Arduino Nano | TB6612FNG | Σκοπός |
|---|---|---|
| D3 | PWMA | PWM ταχύτητας Motor A |
| D4 | AIN1 | Κατεύθυνση Motor A |
| D5 | AIN2 | Κατεύθυνση Motor A |
| D6 | STBY | Enable του driver |
| 5V | VCC | Λογική τροφοδοσία TB6612 |
| GND | GND | Κοινή γείωση |

### Τι κάνει το κάθε pin

| Pin | Περιγραφή |
|---|---|
| PWMA | Ρυθμίζει ταχύτητα με PWM, συνήθως `0` έως `255` |
| AIN1 | Direction bit 1 |
| AIN2 | Direction bit 2 |
| STBY | `LOW` = απενεργοποίηση, `HIGH` = ενεργοποίηση |
| VCC | 5V λογικής |
| GND | Κοινή αναφορά όλων των κυκλωμάτων |

Παράδειγμα φοράς:

```cpp
digitalWrite(AIN1, HIGH);
digitalWrite(AIN2, LOW);
analogWrite(PWMA, 80);
```

Αν ο roller γυρίζει ανάποδα, άλλαξε τη λογική κατεύθυνσης:

```cpp
digitalWrite(AIN1, LOW);
digitalWrite(AIN2, HIGH);
```

ή αντάλλαξε τα καλώδια `AO1` και `AO2`.

## 2. 12V Τροφοδοτικό προς TB6612FNG

Προσοχή: αυτό είναι το κομμάτι που λείπει όταν το Arduino στέλνει PWM αλλά το
μοτέρ δεν έχει δύναμη να γυρίσει.

Στη δεξιά πλευρά του TB6612FNG, από πάνω προς τα κάτω, η σειρά είναι:

```text
VM
VCC
GND
AO1
AO2
BO2
BO1
GND
```

| Τροφοδοτικό 12V | TB6612FNG | Σκοπός |
|---|---|---|
| +12V | VM | Τροφοδοσία κινητήρα |
| GND | GND | Επιστροφή ρεύματος και κοινή γείωση |

Το `VM` είναι μόνο για το `+12V` του μοτέρ. Το `VCC` είναι μόνο για `5V` λογικής.
Μην βάλεις ποτέ `12V` στο `VCC`.

### Κρίσιμη σημείωση γείωσης

Το `GND` του 12V τροφοδοτικού, το `GND` του TB6612 και το `GND` του Arduino Nano
πρέπει να είναι κοινά. Χωρίς κοινή γείωση, τα PWM/direction signals δεν έχουν
σωστή αναφορά.

```text
Arduino GND
    |
TB6612 GND
    |
12V PSU GND
```

## 3. GB37Y3530 Motor προς TB6612FNG

Ο κινητήρας έχει δύο καλώδια ισχύος και τέσσερα καλώδια encoder.

### Motor leads

| Χρώμα | Χρήση |
|---|---|
| Κόκκινο |  Motor Lead (AO1)|
| Μαύρο | Motor Lead (AO2) |
| Μπλε | Encoder A |
| Πράσινο | Encoder B |
| Κίτρινο | Encoder VCC |
| Λευκό | Encoder GND |

### Σύντομος πίνακας χρωμάτων

| Χρώμα καλωδίου | Αντιστοιχεί σε | Σύνδεση σε αυτό το prototype |
|---|---|---|
| Κόκκινο | Motor lead | TB6612 `AO1` |
| Μαύρο | Motor lead | TB6612 `AO2` |
| Μπλε | Encoder A | Arduino Nano `D2` |
| Πράσινο | Encoder B | Arduino Nano `D7` |
| Κίτρινο | Encoder VCC | `5V` |
| Λευκό | Encoder GND | `GND` |

Αν ο roller γυρίζει ανάποδα, άλλαξε πρώτα τη φορά στο software ή αντάλλαξε τα
δύο motor leads `AO1`/`AO2`. Μην αλλάξεις τα καλώδια του encoder για να διορθώσεις
τη φορά του μοτέρ.

### Σύνδεση μοτέρ

| Motor | TB6612FNG |
|---|---|
| Κόκκινο | AO1 |
| Μαύρο | AO2 |

Αν η φορά είναι ανάποδη, προτίμησε πρώτα αλλαγή στο software. Αν χρειάζεται,
αντάλλαξε `AO1` και `AO2`.

## 4. Encoder προς Arduino Nano

| Encoder | Arduino Nano | Σκοπός |
|---|---|---|
| Κίτρινο | 5V | Τροφοδοσία encoder |
| Λευκό | GND | Γείωση encoder |
| Μπλε | D2 | Encoder A / interrupt input |
| Πράσινο | D7 | Encoder B / direction input |

Σημείωση: το `D3` χρησιμοποιείται ήδη για `PWMA`, άρα δεν το χρησιμοποιούμε για
`Encoder B` σε αυτό το wiring. Το `D7` είναι η καθαρή επιλογή για direction
read. Αργότερα, αν θέλουμε πλήρες quadrature decoding με interrupts και στα δύο
κανάλια, μπορούμε να αλλάξουμε pin map ή controller.

### Τι κάνει

| Pin | Περιγραφή |
|---|---|
| Encoder A | Μετρά παλμούς |
| Encoder B | Δίνει κατεύθυνση σε σχέση με το A |
| 5V | Τροφοδοσία encoder |
| GND | Γείωση |

Ο encoder θα χρειαστεί αργότερα για ακριβή έλεγχο RPM και για να ξέρουμε αν ο
roller έχει κολλήσει.

## 5. IR Break Beam #1 - Roller Entrance

Το πρώτο IR beam μπαίνει στην είσοδο του roller και βλέπει πότε μπαίνει μπαλάκι
στον collector.

### Receiver, 3 καλώδια

| Receiver | Arduino Nano |
|---|---|
| Κόκκινο | 5V |
| Μαύρο | GND |
| Λευκό | D9 |

### Emitter, 2 καλώδια

| Emitter | Arduino Nano |
|---|---|
| Κόκκινο | 5V |
| Μαύρο | GND |

## 6. IR Break Beam #2 - Roller Exit

Το δεύτερο IR beam μπαίνει στην έξοδο του roller και βλέπει ότι το μπαλάκι έφτασε
προς το flywheel ή το επόμενο στάδιο.

### Receiver, 3 καλώδια

| Receiver | Arduino Nano |
|---|---|
| Κόκκινο | 5V |
| Μαύρο | GND |
| Λευκό | D10 |

### Emitter, 2 καλώδια

| Emitter | Arduino Nano |
|---|---|
| Κόκκινο | 5V |
| Μαύρο | GND |

### IR input mode

Τα Adafruit IR break beam receivers έχουν open-collector output. Στο Arduino
χρησιμοποίησε internal pull-up:

```cpp
pinMode(9, INPUT_PULLUP);
pinMode(10, INPUT_PULLUP);
```

Με pull-up, το signal μπορεί να φαίνεται ανάποδο λογικά. Δηλαδή θα δεις συνήθως
`LOW` όταν η δέσμη είναι σπασμένη/blocked και `HIGH` όταν η δέσμη είναι καθαρή.
Αυτό είναι το αντίστροφο από το σχόλιο που είχαμε αρχικά στα collector sketches.

## 7. Τελική Χρήση Στο Tennis Robot

| Sensor / Module | Θέση | Ρόλος |
|---|---|---|
| IR #1 | Roller entrance | Βλέπει μπαλάκι να μπαίνει |
| IR #2 | Roller exit | Βλέπει ότι το μπαλάκι έφτασε στο επόμενο στάδιο |
| Encoder | Collector motor | Μετρά RPM και βοηθά στο jam detection |
| TB6612FNG | Collector motor driver | Ελέγχει φορά και PWM ταχύτητα |

Η βασική λογική του collector είναι:

```text
IR #1 triggered
    -> ball entered roller
    -> keep roller running

IR #2 triggered
    -> ball reached exit/flywheel path
    -> collection transfer confirmed

Encoder pulses missing while PWM > 0
    -> possible jam or wiring/power fault
```

## 8. Τελική Εικόνα Συστήματος

Collector Linux control diagram

```text
12V PSU
    |
    v
TB6612 VM
    |
    v
GB37Y3530 Motor
    |
    v
Collector Roller

Arduino Nano
    |-- TB6612 control: D3, D4, D5, D6
    |-- Encoder: D2, D7
    |-- IR Beam #1: D9
    |-- IR Beam #2: D10
```

## 9. Πρώτο Power-On Checklist

Πριν βάλεις 12V στο `VM`:

1. Επιβεβαίωσε ότι `Arduino GND`, `TB6612 GND` και `12V PSU GND` είναι κοινά.
2. Επιβεβαίωσε ότι το `VCC` του TB6612 είναι στο `5V`, όχι στο `12V`.
3. Επιβεβαίωσε ότι το `VM` του TB6612 είναι στο `+12V`.
4. Επιβεβαίωσε ότι το `STBY` πηγαίνει σε pin που γίνεται `HIGH`.
5. Ξεκίνα με χαμηλό PWM, π.χ. `50` έως `80`, όχι κατευθείαν `255`.
6. Κράτα το μοτέρ χωρίς μηχανικό φορτίο στο πρώτο test.
7. Έλεγξε αν ο TB6612 ζεσταίνεται πολύ.
8. Αν ο roller γυρίζει ανάποδα, άλλαξε direction pins ή `AO1`/`AO2`.

### Έλεγχος με πολύμετρο

Πριν συνδέσεις μοτέρ ή πριν δώσεις PWM, μέτρα πάνω στα pins του TB6612:

| Μέτρηση | Αναμενόμενο |
|---|---|
| `VCC` προς `GND` | περίπου 5V |
| `VM` προς `GND` | περίπου 12V |
| `Arduino GND` προς `TB6612 GND` | συνέχεια / σχεδόν 0 ohm |
| `AO1` και `AO2` | μόνο προς τα δύο καλώδια του μοτέρ |

Αν δεις 12V στο `VCC`, σταμάτα. Αν δεν δεις κοινή γείωση μεταξύ Arduino και
TB6612, σταμάτα και διόρθωσε τη γείωση πριν συνεχίσεις.

## 10. Προσοχή Για Ρεύμα Μοτέρ

Ο GB37Y3530 μπορεί να έχει μεγάλο stall current. Ο TB6612FNG είναι μικρός driver
και δεν πρέπει να χρησιμοποιηθεί για παρατεταμένο stall ή βαριά μηχανική φόρτιση.

Για το πρώτο bench test:

- χαμηλό PWM,
- μικρή διάρκεια,
- χωρίς μπλοκαρισμένο roller,
- έλεγχος θερμοκρασίας driver,
- άμεση διακοπή αν ο driver ζεσταθεί, κάνει reset, ή το μοτέρ τραβάει απότομα.

Αν ο collector χρειάζεται πολλή ροπή ή κολλάει συχνά σε μπαλάκι, θα χρειαστεί πιο
δυνατός motor driver για το τελικό build.

## 11. Συνοπτικός Pin Map

| Arduino Nano Pin | Χρήση |
|---|---|
| D2 | Encoder A |
| D3 | TB6612 PWMA |
| D4 | TB6612 AIN1 |
| D5 | TB6612 AIN2 |
| D6 | TB6612 STBY |
| D7 | Encoder B |
| D9 | IR Break Beam #1 receiver signal |
| D10 | IR Break Beam #2 receiver signal |
| 5V | TB6612 VCC, encoder VCC, IR sensors VCC |
| GND | Common ground |

## 12. Arduino Sketches Και Tests

Τα sketches για bring-up και επιβεβαίωση καλής λειτουργίας είναι στο:

```text
arduino/collector/
```

Προτεινόμενη σειρά:

1. `01_ir_beam_test` - ελέγχει τα 2 IR break beams χωρίς 12V στο `VM`.
2. `02_encoder_hand_test` - ελέγχει encoder pulses γυρίζοντας τον άξονα με το χέρι.
3. `03_motor_tb6612_test` - ελέγχει ότι ο TB6612 γυρίζει το μοτέρ με χαμηλό PWM.
4. `04_collector_smoke_test` - ελέγχει motor, encoder και IR beams μαζί.

### Επιβεβαιωμένη δοκιμή motor driver

Το `06_motor_driver_wiring_check` πέρασε σε πραγματικό collector wiring στις
28/06/2026 με:

- Arduino Nano → TB6612FNG → 12V motor,
- `D3=PWMA`, `D4=AIN1`, `D5=AIN2`, `D6=STBY`,
- Serial Monitor `9600 baud`, χωρίς line ending,
- `START_PWM=255`, `MAX_SAFE_PWM=255`,
- pulse διάρκειας `300 ms`.

Η επιτυχία επιβεβαιώνει το control path και την κοινή γείωση για αυτή τη
συνδεσμολογία. Δεν αποτελεί ακόμη validation των IR sensors ή του encoder.
5. `05_wiring_diagnostic` - δείχνει live status για IR, encoder και TB6612 wiring, με ασφαλές σύντομο motor pulse μέσω της εντολής `p`.
6. `06_motor_driver_wiring_check` - απομονώνει μόνο Arduino Nano, TB6612FNG, 12V τροφοδοσία και motor, χωρίς IR/encoder.

## 13. Τρέχον Συμπέρασμα

Το πλήρες wiring του πρώτου collector prototype είναι έτοιμο ως σχέδιο. Το μόνο
κομμάτι που λείπει όταν βλέπεις PWM messages αλλά το μοτέρ δεν γυρίζει είναι:

```text
+12V -> TB6612 VM
GND  -> TB6612 GND, κοινό με Arduino GND
```

Μόλις μπει αυτό, ο TB6612 θα έχει και λογική τροφοδοσία (`VCC`) και τροφοδοσία
μοτέρ (`VM`), άρα ο collector motor μπορεί να γυρίσει.

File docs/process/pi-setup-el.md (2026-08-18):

# WS2 — Pi bring-up (Ubuntu 24.04 aarch64 / ROS 2 Jazzy)

Στόχος (Gate WS2): το workspace **χτίζει καθαρά** στο Pi, ένα control node
**ξεκινά idle** χωρίς sim, και το **onnxruntime φορτώνει** σε ARM64. Δεν
εγκαθίσταται Gazebo — η προσομοίωση μένει στο PC και φτάνει στο Pi μέσω δικτύου
(WS3).

Αρχιτεκτονική: **PC = Gazebo + ros_gz bridge** (sensors, `/clock`, δέχεται
`/cmd_vel*`) · **Pi = controller_node + perception_node + Nav2 + slam_toolbox +
web console**. Δες [pi-deployment-plan-el.md](pi-deployment-plan-el.md).

## Προϋποθέσεις
- Raspberry Pi με **Ubuntu 24.04 aarch64** (`lsb_release -a`, `uname -m`).
- Δίκτυο + το repo cloned στο Pi (ίδιο path δεν χρειάζεται — το `TENNIS_ROBOT_ROOT`
  προκύπτει από το script).
- ≥ 8 GB κάρτα/δίσκος (η nav2 + slam apt εγκατάσταση θέλει χώρο).

## Βήματα

```bash
git clone <repo> tennis-robot && cd tennis-robot   # ή pull αν υπάρχει ήδη

# 1) Πρώτη φορά (εγκαθιστά και το ROS 2 Jazzy ros-base):
INSTALL_ROS=true ./scripts/setup_pi.sh

# ή, αν το ROS 2 Jazzy υπάρχει ήδη:
./scripts/setup_pi.sh
```

Το `setup_pi.sh` (idempotent):
1. (προαιρετικά) προσθέτει το ROS 2 apt repo + `ros-jazzy-ros-base`.
2. εγκαθιστά **μόνο τα Pi-side ROS πακέτα** — navigation2, nav2-bringup,
   slam-toolbox, robot-localization, twist-mux, robot-state-publisher, tf2, xacro,
   rmw-fastrtps-cpp + build tools (**όχι** Gazebo/ros_gz/ros2_control).
3. `rosdep install` με `--skip-keys` για τα sim-only deps (τρέχουν στο PC).
4. `pip install` τα runtime deps (numpy, opencv-headless, duckdb, **onnxruntime**)
   στο system Python (`--user --break-system-packages`, PEP 668).
5. `colcon build` τα 3 πακέτα → `ros2_ws/install_jazzy/`.

## Επαλήθευση (Gate WS2)

```bash
source /opt/ros/jazzy/setup.bash
source ros2_ws/install_jazzy/setup.bash

# (α) python runtime deps φορτώνουν σε ARM64
python3 -c 'import onnxruntime, duckdb, cv2, numpy; print("py deps OK")'

# (β) το C++ plugin package είναι εγκατεστημένο
ros2 pkg prefix tennis_robot_collection_controller

# (γ) ένα control node ξεκινά idle χωρίς sim (Ctrl-C να το κλείσεις)
export TENNIS_ROBOT_ROOT="$PWD"
ros2 run tennis_robot controller_node
```

Gate περνά όταν: (α) τυπώνει `py deps OK`, (β) δίνει path, (γ) το controller_node
μένει ζωντανό σε idle (δεν κρασάρει — δεν χρειάζεται sensors για να idle-άρει).

## Troubleshooting

- **onnxruntime ARM64 (Ρίσκο #1):** το wheel υπάρχει στο PyPI για `onnxruntime>=1.20`
  σε aarch64. Αν το `pip install` δεν το βρει: δοκίμασε piwheels
  (`pip install onnxruntime --extra-index-url https://www.piwheels.org/simple`) ή
  apt (`sudo apt install python3-onnxruntime` αν υπάρχει). Ο ball detector είναι
  **fail-loud** χωρίς αυτό — το `perception_node` δεν ξεκινά. (Στο distributed
  setup το perception μπορεί προσωρινά να τρέχει στο PC μέχρι να λυθεί.)
- **colcon build killed (OOM) σε Pi με λίγη RAM:** χτίζουμε μόνο 3 μικρά πακέτα
  (η nav2 έρχεται από apt, όχι από source), αλλά αν συμβεί, χτίσε σειριακά:
  `cd ros2_ws && MAKEFLAGS=-j1 colcon build --executor sequential --parallel-workers 1 \
  --build-base build_jazzy --install-base install_jazzy --packages-select \
  tennis_robot_msgs tennis_robot_collection_controller tennis_robot`. Πρόσθεσε swap
  αν χρειαστεί.
- **rosdep unresolved keys:** τα `ros_gz_*`, `gz_ros2_control`, οι ros2_control
  spawners **skip-άρονται επίτηδες** (τρέχουν στο PC). Το warning είναι αναμενόμενο.
- **`No module named 'em'/'lark'` στο build:** uv-managed python shadow-άρει το
  system — το script βάζει `/usr/bin` πρώτο, αλλά σε νέο shell κάνε
  `export PATH=/usr/bin:$PATH` πριν το build.

## Επόμενο — WS3 (distributed ROS 2)
PC sim ↔ Pi control μέσω κοινού `ROS_DOMAIN_ID` + ίδιο RMW + ίδιο LAN. Όλα τα Pi
nodes `use_sim_time:=true` κλειδωμένα στο `/clock` του PC. Χρειάζεται ένα
**control-only launch** για το Pi (partition των nodes PC↔Pi) — αυτό είναι το
πρώτο βήμα του WS3.

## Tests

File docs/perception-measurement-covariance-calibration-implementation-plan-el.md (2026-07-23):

# Implementation Plan: perception measurement covariance calibration

> Η φάση αυτή προηγείται του `ScanSnapshotBuilder` και είναι ανεξάρτητη από
> Gazebo/physical calibration evidence.

## Phase C1 — Schema, artifact model και health contract

**Implementation**

- Update `BallDetection.msg` και `BallDetectionArray.msg` με το documented
  metadata/health schema.
- Add `perception_covariance_calibration.py` with artifact parser/validator,
  `range_depth_quality_diagonal_v1` model interface and typed rejection.
- Update perception producer wiring to load artifact explicitly and publish
  only non-spatial detections/heartbeat while unhealthy.
- Add health fields to every `BallDetectionArray` heartbeat.

**Tests**

- `tests/test_perception_covariance_calibration.py`: schema parsing, finite,
  symmetric PSD covariance, monotonic range/quality behavior, invalid artifact
  and out-of-domain rejection.
- Update `tests/test_perception_contract_ros.py`: message metadata, health
  status and no-spatial behavior while artifact is unavailable.

**Gate**

- Synthetic valid artifact proves the model/contract behavior.
- Missing, invalid and out-of-domain artifact/input never publish
  `has_spatial=true`.
- No calibrated artifact is shipped or enabled by this phase.

## Phase C2 — Gazebo calibration evidence

Create and validate a Gazebo artifact against the documented
[`gazebo calibration scenario`](gazebo-perception-covariance-calibration-scenario-el.md)
and its acceptance metrics. The evidence capture must compare raw fusion XYZ
with timestamp-aligned `/sim/balls` ground truth, record every rejection, fit
only from measured errors, and emit a versioned report. The artifact gate
requires a conservative per-axis check over every accepted sample in its
declared domain. Only after this gate may Gazebo publish spatial targets and
unblock collection-route Phase 2.

## Phase C3 — Physical OAK-D calibration evidence

Create and validate the physical artifact. This gate is required only for
physical runs and does not block Gazebo Phase 2.

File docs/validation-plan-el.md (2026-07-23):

# Tennis Robot Validation and Implementation Plan

Αυτό είναι το βασικό πλάνο υλοποίησης και validation για το tennis robot.
Η κεντρική στρατηγική είναι simulation-first, με σταδιακή μεταφορά των
αποφάσεων σε μικρό φυσικό prototype και μετά σε πραγματικό γήπεδο.

```text
Webots = architecture + algorithm validation
Real prototype = sensing + mechanics validation
Real court = product-environment validation
```

## 1. Design Direction

Το robot χρησιμοποιεί καθαρό διαχωρισμό ευθυνών ανάμεσα στα sensors:

- **LiDAR** για navigation, obstacle avoidance, mapping και safety.
- **OAK-D / camera** για ball detection, person recognition και semantic perception.
- **Low front proximity / ToF sensors** για τελική επιβεβαίωση κοντά στον συλλέκτη.

Η βασική αρχιτεκτονική απόφαση είναι:

```text
LiDAR = navigation, safety, obstacle map
OAK-D = ball/person recognition
Low front sensors = final collection confirmation
```

Το LiDAR δεν χρησιμοποιείται ως κύριο sensor για αναγνώριση μπαλών. Αυτό
μειώνει την πολυπλοκότητα, κρατάει το simulation ρεαλιστικό και βοηθάει το
prototype να επικεντρωθεί στα σωστά ρίσκα.

## 2. Target Sensor Layout

### Navigation LiDAR

Το LiDAR τοποθετείται περίπου στα **25-35 cm** από το έδαφος.

Χρησιμοποιείται για:

- ανίχνευση εμποδίων,
- αποφυγή ανθρώπων και ποδιών,
- δημιουργία occupancy map ή obstacle sectors,
- επιλογή ασφαλούς διαδρομής,
- υποστήριξη search pattern.

Δεν χρησιμοποιείται ως κύριο sensor για αναγνώριση μπαλών.

### OAK-D Camera

Η OAK-D τοποθετείται περίπου στα **40-60 cm**, με ελαφριά κλίση προς τα κάτω.

Χρησιμοποιείται για:

- αναγνώριση tennis balls,
- εκτίμηση θέσης μπάλας,
- person detection,
- επιβεβαίωση στόχου πριν το robot κινηθεί προς αυτόν.

### Front Low Sensors

Χαμηλοί proximity ή ToF sensors τοποθετούνται μπροστά στον μηχανισμό συλλογής.

Χρησιμοποιούνται για:

- τελική επιβεβαίωση ότι η μπάλα βρίσκεται μπροστά στον συλλέκτη,
- αποφυγή μικρών χαμηλών εμποδίων,
- υποστήριξη του collection mechanism.

## 3. Phase 1 - Webots Simulation

### Goal

Να επιβεβαιωθεί ότι η αρχιτεκτονική, το navigation logic και το search behavior
είναι λειτουργικά πριν περάσουμε σε πραγματικό prototype.

### Scope

Το Webots simulation πρέπει να απαντήσει:

- Μπορεί το robot να ψάξει συστηματικά το γήπεδο;
- Μπορεί να αποφύγει ανθρώπους και εμπόδια;
- Μπορεί να κινηθεί προς detected ball;
- Μπορεί να οργανώσει search pattern;
- Πού πρέπει να μπουν LiDAR, OAK-D και low sensors;

### Simulation Components

Το simulation πρέπει να περιλαμβάνει:

- tennis court environment,
- robot base,
- 2D 360-degree LiDAR στα 25-35 cm,
- RGB ή RGB-D camera ως OAK-D approximation,
- tennis balls ως μικρά objects στο court,
- ανθρώπους ή moving obstacles,
- απλά static obstacles,
- collector placeholder μπροστά στο robot.

### Core Behavior State Machine

```text
Idle
↓
Require / Load Court Knowledge Model
↓
Scan Selected Side Matrix
↓
Plan Collection
↓
Detect Candidate Ball
↓
Validate Path
↓
Navigate to Ball
↓
Final Approach
↓
Collect / Simulated Collect
↓
Resume Plan Or Rescan
```

### Webots Implementation Milestones

1. Confirm current simulated sensor layout and document exact mount heights.
2. Add or validate obstacle sectors from LiDAR.
3. Add Court Knowledge Model storage and require a valid Court Knowledge Model before collection, following `docs/court-knowledge-model-specification.md`.
4. Add matrix-based side scan for the selected collection side.
5. Connect camera detections to matrix cells and planned targets.
6. Add path validation before committing to a planned target.
7. Follow the active continuous-route behavior in `docs/collection-route-rules-el.md`.
8. Add simulated collection event.
9. Add structured telemetry logs for Court Knowledge Model status, matrix scan, planning decisions and failures.
10. Add repeatable smoke/regression scenarios.

### DoD - Webots Simulation

Η φάση θεωρείται ολοκληρωμένη όταν:

1. Το robot δεν ξεκινά collection χωρίς valid Court Knowledge Model για το selected court.
2. Το Court Knowledge Model παράγει court geometry, fence geometry, obstacle map, accessibility map και traversable route information.
3. Το robot μπορεί να εκτελέσει side scan και να ενημερώσει cells με ball observations.
4. Το LiDAR δημιουργεί usable obstacle map ή τουλάχιστον reliable obstacle sectors.
5. Το robot σταματά ή αλλάζει πορεία όταν υπάρχει άνθρωπος/εμπόδιο μπροστά του.
6. Η camera μπορεί να εντοπίσει simulated tennis balls.
7. Το robot μπορεί να παράγει ordered collection plan από matrix data.
8. Το robot μπορεί να κινηθεί προς planned target χωρίς να αγνοεί εμπόδια.
9. Το robot μπορεί να κάνει final approach με μειωμένη ταχύτητα.
10. Το simulation δείχνει καθαρά αν η θέση LiDAR/OAK-D είναι λογική.
11. Υπάρχουν logs για Court Knowledge Model status, matrix scan, planned targets, obstacle events, navigation decisions και failed detections.
12. Υπάρχει documented limitation list για όσα δεν μπορεί να αποδείξει το Webots.

### Suggested Webots Metrics

- detection success rate σε known simulated balls,
- false positive count ανά scenario,
- average time to first ball,
- average time to collect/simulate collect,
- obstacle stop/replan count,
- blocked-target recovery count,
- number of successful full search loops.

## 4. Phase 2 - Small Physical Prototype

### Goal

Να επιβεβαιωθεί ότι τα πραγματικά sensors και η βασική μηχανική συμπεριφορά
δουλεύουν εκτός simulation.

### Scope

Το prototype δεν χρειάζεται να είναι πλήρες προϊόν. Χρειάζεται να αποδείξει:

- ότι η OAK-D βλέπει πραγματικά tennis balls,
- ότι το LiDAR βλέπει αξιόπιστα ανθρώπους και εμπόδια,
- ότι το robot μπορεί να κινηθεί προς στόχο,
- ότι ο μηχανισμός συλλογής έχει ρεαλιστική βάση.

### Prototype Components

- mobile base,
- 2D LiDAR,
- OAK-D camera,
- low front ToF/proximity sensors,
- basic collection mechanism,
- onboard computer ή external control laptop,
- emergency stop.

### Physical Prototype Milestones

1. Bench-test OAK-D ball detection.
2. Bench-test LiDAR obstacle/person sectors.
3. Bench-test low front sensor trigger zone.
4. Drive toward a known fixed target in a controlled indoor area.
5. Drive toward a detected ball in a controlled indoor area.
6. Stop on human/obstacle intrusion.
7. Attempt simple one-ball collection.
8. Feed real failures back into Webots scenarios.

### DoD - Physical Prototype

Η φάση θεωρείται ολοκληρωμένη όταν:

1. Η OAK-D εντοπίζει tennis balls σε διαφορετικές θέσεις και αποστάσεις.
2. Το LiDAR εντοπίζει αξιόπιστα ανθρώπινα πόδια και μεγάλα εμπόδια.
3. Το robot μπορεί να κινηθεί προς detected ball σε ελεγχόμενο χώρο.
4. Το robot σταματά όταν άνθρωπος μπει μπροστά του.
5. Ο μηχανισμός συλλογής μπορεί να συλλέξει τουλάχιστον μία μπάλα σε απλό σενάριο.
6. Έχουν καταγραφεί failure cases για κακό φωτισμό, σκιά, μπάλα κοντά σε γραμμή, μπάλα κοντά σε δίχτυ, άνθρωπο που κινείται και false positive object.
7. Τα πραγματικά failures επιστρέφουν ως input για βελτίωση του simulation.

## 5. Phase 3 - Real Court Tests

### Goal

Να ελεγχθεί αν το robot δουλεύει σε πραγματικό tennis court.

### Test Scenarios

- άδειο γήπεδο με 5-10 μπάλες,
- γήπεδο με άνθρωπο που κινείται,
- μπάλες κοντά σε γραμμές,
- μπάλες κοντά στο δίχτυ,
- μπάλες σε σκιά,
- μπάλες κοντά σε εμπόδια,
- διαφορετικές επιφάνειες γηπέδου,
- διαφορετικές συνθήκες φωτισμού.

### DoD - Real Court Validation

Η φάση θεωρείται ολοκληρωμένη όταν:

1. Το robot μπορεί να βρει και να προσεγγίσει μπάλες σε πραγματικό γήπεδο.
2. Το robot αποφεύγει ανθρώπους και εμπόδια με ασφαλή τρόπο.
3. Το robot μπορεί να συνεχίσει search μετά από failed detection ή blocked path.
4. Το robot δεν βασίζεται αποκλειστικά σε ένα sensor για κρίσιμες αποφάσεις.
5. Υπάρχει καταγραφή detection success rate, false positives, missed balls, average time to find ball, collision/near-collision events και successful collections.
6. Τα failure cases έχουν ταξινομηθεί σε sensing failures, navigation failures, mechanical collection failures και decision logic failures.
7. Το mission dashboard, όπως ορίζεται στο `docs/mission-dashboard-plan-el.md`, δείχνει progress, safety counters και mission timeline χωρίς άνοιγμα raw logs.

## 6. Phase 4 - Improve Simulation Based on Real Failures

### Goal

Το simulation να γίνει πιο χρήσιμο επειδή θα βασίζεται σε πραγματικές αποτυχίες.

### Improvements

Μετά τα real tests, το Webots simulation πρέπει να εμπλουτιστεί με:

- realistic ball positions,
- moving humans,
- blind spots,
- false positive objects,
- lighting approximation όπου είναι εφικτό,
- obstacle scenarios από πραγματικά tests,
- failed approach scenarios,
- collection edge cases.

### DoD - Simulation Feedback Loop

Η φάση θεωρείται ολοκληρωμένη όταν:

1. Κάθε σημαντικό real-world failure έχει αντίστοιχο simulation scenario.
2. Το simulation χρησιμοποιείται για regression testing.
3. Κάθε νέα αλλαγή στο navigation/search logic δοκιμάζεται πρώτα στο Webots.
4. Τα simulation tests μπορούν να δείξουν αν μια αλλαγή βελτιώνει ή χαλάει το behavior.
5. Υπάρχει repeatable test suite με βασικά scenarios.

## 7. Overall Product DoD

Το project μπορεί να θεωρηθεί validated σε concept level όταν:

1. Το Webots αποδεικνύει ότι η αρχιτεκτονική και ο αλγόριθμος έχουν συνοχή.
2. Το physical prototype αποδεικνύει ότι τα sensors δουλεύουν σε πραγματικές συνθήκες.
3. Τα real court tests αποδεικνύουν ότι το robot μπορεί να λειτουργήσει στο φυσικό περιβάλλον του.
4. Το robot μπορεί να ψάχνει το γήπεδο, να εντοπίζει μπάλες, να αποφεύγει ανθρώπους/εμπόδια, να προσεγγίζει μπάλα, να προσπαθεί να τη συλλέξει και να συνεχίζει μετά από αποτυχία.
5. Οι βασικές αβεβαιότητες είναι γνωστές και καταγεγραμμένες.
6. Υπάρχει καθαρός διαχωρισμός ανάμεσα σε simulation validation, sensing validation, mechanical validation και safety validation.

## 8. Phase Gates

Για να αποφύγουμε premature hardware complexity, κάθε phase ανοίγει μόνο όταν το
προηγούμενο έχει καθαρό evidence:

| Gate | Από | Προς | Minimum evidence |
| --- | --- | --- | --- |
| G1 | Webots architecture | Physical prototype | Search, detection, obstacle response και final approach δουλεύουν σε repeatable scenarios. |
| G2 | Physical prototype | Real court tests | Τα πραγματικά sensors βλέπουν μπάλα/άνθρωπο και το robot σταματά αξιόπιστα σε ελεγχόμενο χώρο. |
| G3 | Real court tests | Simulation feedback loop | Υπάρχει categorized failure log από πραγματικό γήπεδο. |
| G4 | Feedback loop | Iterative product work | Τα σημαντικά real failures έχουν γίνει regression scenarios. |

## 9. Immediate Next Steps

1. Κλείδωμα sensor layout στο Webots με documented heights και angles.
2. Σύνδεση του υπάρχοντος camera ball detection με target-selection telemetry.
3. Επιβεβαίωση LiDAR obstacle sectors και stop/replan behavior.
4. Δημιουργία repeatable half-court search smoke test.
5. Καταγραφή limitation list για Webots, ώστε να είναι καθαρό τι πρέπει να αποδειχθεί μόνο στο prototype.

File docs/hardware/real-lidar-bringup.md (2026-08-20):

# Real LiDAR bring-up on Raspberry Pi

Status: **hardware implementation and office interface validation complete**.
This document records evidence
for the LiDAR hardware interface milestone. It is not evidence for SLAM,
navigation, localisation, or outdoor/court performance.

The collection simulation planner, executor, and controller are frozen for this
milestone and must not be changed.

## L1 — Existing simulation contract

The simulated source is the generic Gazebo Harmonic `gpu_lidar` sensor named
`front_lidar`, declared by the `rplidar_c1_mount` URDF macro. Gazebo publishes a
`gz.msgs.LaserScan` on `/gz/lidar`; `ros_gz_bridge` maps it to the canonical ROS
topic `/scan` as `sensor_msgs/msg/LaserScan`.

The following values are the **declared simulation configuration**. Fields that
only exist after Gazebo-to-ROS conversion are deliberately not guessed and are
listed separately under runtime evidence.

| Property | Simulation |
| --- | --- |
| topic | `/scan` (from Gazebo `/gz/lidar`) |
| message type | `sensor_msgs/msg/LaserScan` |
| frame_id | `lidar_link` |
| configured rate | `31.25 Hz` (`32 ms` period) |
| angle range | `-pi .. +pi rad` (360 degrees) |
| angular resolution | configured 500 samples/revolution, nominally `2pi / 500 = 0.012566 rad` (`0.72 deg`) |
| samples/scan | `500` |
| min range | `0.15 m` |
| max range | `12.0 m` |
| range resolution | `0.01 m` |
| noise model | Gaussian, mean `0 m`, standard deviation `0.005 m` |
| QoS | no override in `gazebo/bridge_config.yaml`; effective publisher QoS must be captured with `ros2 topic info /scan --verbose` |

### Runtime-derived simulation fields

An existing Control Panel snapshot from the frozen simulation contains 500
ranges, `angle_increment=0.01259155385196209`, angle limits
`-3.141592741..+3.141592741`, and range limits `0.150000006..12.0 m`. The
configured 31.25 Hz remains a declaration, not a newly measured rate: the
simulation was not started for this hardware milestone.

The Jazzy `ros_gz_bridge` conversion source explicitly sets `scan_time=0` and
`time_increment=0`, because those fields do not exist in
`gz::msgs::LaserScan`. It copies the Gazebo ranges and intensities without
changing their numerical values. The repository bridge configuration does not
select a special QoS profile, so the bridge uses its default-constructed ROS 2
QoS (reliable, volatile). These source-derived facts and the archived snapshot
are sufficient for the interface comparison; they are not a new simulator
validation run.

For a future fresh simulation capture, use the following read-only commands;
do not modify the simulator to make it match the hardware:

```bash
ros2 topic info /scan --verbose
ros2 topic hz /scan
ros2 topic echo /scan --once --field header
ros2 topic echo /scan --once --field angle_min
ros2 topic echo /scan --once --field angle_max
ros2 topic echo /scan --once --field angle_increment
ros2 topic echo /scan --once --field time_increment
ros2 topic echo /scan --once --field scan_time
ros2 topic echo /scan --once --field range_min
ros2 topic echo /scan --once --field range_max
ros2 topic echo /scan --once --field ranges
```

The configured `31.25 Hz` must not be reported as an observed measurement.

### TF contract

The URDF publishes a fixed transform:

```text
base_link -> lidar_link
xyz = (-0.42, 0.0, 0.498) m
rpy = (0.0, 0.0, 0.0) rad
```

The Gazebo ray sensor itself has a local pose of `(0, 0, 0.035, 0, 0, 0)` inside
`lidar_link` so the simulated rays do not originate inside the visual housing,
while the message is labelled `lidar_link`. This 35 mm vertical simulation-only
offset does not change the planar scan orientation, but it is recorded here so
it is not mistaken for a measured physical mounting transform.

### Current consumers

Direct ROS consumers of canonical `/scan` found in the source tree are:

- `controller_node`: depth 1 using the rclpy default reliable/volatile QoS;
- `sensor_snapshot_node`: best-effort, volatile, keep-last depth 1; this is the
  adapter that feeds the Control Panel sensor JSON;
- `court_survey_v2_node`: best-effort, volatile, keep-last depth 1;
- `slam_toolbox`: `scan_topic: /scan`;
- Nav2 local and global costmap obstacle layers: `LaserScan` source `/scan`;
- RViz: best-effort, volatile, keep-last depth 5.

The two domain-bridge configurations also forward `/scan` during distributed
simulation. They are transport boundaries, not application consumers.

The existing Control Panel Diagnostics page does not subscribe to ROS directly.
It renders `front_lidar` snapshots written by `sensor_snapshot_node`; its current
plot already consumes `angle_min`, `angle_increment`, `range_min`, `range_max`,
and the ranges array without a Gazebo/hardware branch.

### Canonical-topic decision

`/scan` is already the sole downstream LiDAR contract. No new canonical topic is
justified. A physical driver should publish or remap into `/scan`, with any
hardware-specific normalization kept at the driver/adapter boundary.

## L2 — Physical device evidence

Repository names and old configuration are **not sufficient hardware
identification**. In particular, references to `RPLIDAR C1`, `sllidar_ros2`,
`/dev/ttyUSB0`, `460800`, and `Standard` mode in the current URDF, SLAM comments,
BOM, and `real_sensors.launch.py` started this milestone as unverified prior
assumptions.

### Enumeration captured 2026-08-19

Read-only enumeration was run over the repository's established SSH route to
the physical Pi. Gazebo and the robot runtime were not started.

| Property | Observed value |
| --- | --- |
| Pi hostname | `tennisserver` |
| OS | Ubuntu 24.04.4 LTS (`noble`) |
| kernel/architecture | `6.8.0-1060-raspi`, `aarch64` / `arm64` |
| USB device | `10c4:ea60 Silicon Labs CP210x UART Bridge` |
| kernel driver | `cp210x` |
| Linux device | `/dev/ttyUSB0` |
| stable device path | `/dev/serial/by-id/usb-Silicon_Labs_CP2102N_USB_to_UART_Bridge_Controller_3c21860b3b70f01184b98a301045c30f-if00-port0` |
| USB serial | `3c21860b3b70f01184b98a301045c30f` |
| permissions | `crw-rw---- root:dialout` |
| runtime user | `thanos`, member of `dialout`; read/write access verified after fresh login |
| installed LiDAR ROS package | none in the persistent Jazzy workspace; pinned upstream driver built successfully in `/tmp` |

This proves that a unique CP2102N serial interface is connected and gives us a
stable existing `by-id` path, so a custom udev naming rule is not currently
needed. It does **not**, by itself, prove which LiDAR model is behind the generic
USB-to-UART bridge.

The purchase record identifies the ordered unit as a Waveshare/Slamtec RPLIDAR
C1, and the C1 datasheet specifies 460800 baud. A non-scanning Slamtec
`GET_DEVICE_INFO` query at that baud returned model ID `0x41`, firmware `1.02`,
hardware revision `18`, and sensor serial
`6E4DE0F8C2E29AD2C1819FF59DFC4E1E`. Model `0x41` is the RPLIDAR C1. The exact
physical device is therefore confirmed as **Slamtec RPLIDAR C1**.

The runtime user was added to `dialout`. A fresh SSH login reports membership in
group 20 (`dialout`) and read/write access through the stable `by-id` path. No
root-run driver, `chmod 777`, or custom udev rule is required.

### Reproduction commands

The initial capture used:

```bash
uname -a
dpkg --print-architecture
lsb_release -a
lsusb
ls -l /dev/ttyUSB* /dev/ttyACM* 2>/dev/null
id
```

The device-specific capture used:

```bash
udevadm info --query=all --name=/dev/ttyUSB0
udevadm info --attribute-walk --name=/dev/ttyUSB0
usb-devices
```

L2 is closed: model, USB identity, stable path, baud rate, permissions, and
non-root access are now evidenced.

## L3 — Persistent dependency and Pi-only ROS 2 bring-up

The official [`Slamtec/sllidar_ros2`](https://github.com/Slamtec/sllidar_ros2)
driver is source-pinned to commit
`34300099fadfc772965962dec837bf436706188f` in `ros2_ws/lidar.repos`.
`scripts/import_lidar_dependencies.sh` restores that exact checkout under
`ros2_ws/src/sllidar_ros2`, verifies `HEAD`, and applies the minimal
repository-managed `ros2_ws/patches/sllidar_ros2-clean-shutdown.patch`. The
patch releases the SDK driver and caller-owned channel on the successful exit
path. The importer verifies the resulting source SHA-256 and refuses staged or
unexpected local changes. The imported checkout plus `build_jazzy`,
`install_jazzy`, and `log_jazzy` are gitignored; arbitrary upstream or generated
artifacts are not vendored.

On native Ubuntu 24.04 ARM64 with ROS 2 Jazzy:

```bash
cd ~/tennis-robot
./scripts/setup_pi.sh
source /opt/ros/jazzy/setup.bash
source ros2_ws/install_jazzy/setup.bash
ros2 pkg prefix sllidar_ros2
```

`setup_pi.sh` installs `python3-vcstool`, imports the pin before `rosdep`, and
builds `sllidar_ros2` with the robot packages. A targeted clean verification on
the physical Pi completed both `sllidar_ros2` and `tennis_robot` successfully in
24.5 seconds; only upstream SDK compiler warnings were emitted.

Only the repository-managed LiDAR launch was run in isolated
`ROS_DOMAIN_ID=77`. Gazebo, the simulation bridge, controller, SLAM, Nav2,
collection nodes, and drive motors were not started by this validation. The
driver reported:

```text
SLLidar SDK Version: 2.1.0
S/N: 6E4DE0F8C2E29AD2C1819FF59DFC4E1E
Firmware: 1.02
Hardware: 18
Health: OK
Mode: Standard
Sample rate: 5 kHz
Driver max distance: 16.0 m
Scan frequency: 10.0 Hz
```

The repository-managed live run produced:

| Property | Physical C1 observation |
| --- | --- |
| topic/type | `/scan`, `sensor_msgs/msg/LaserScan` |
| frame_id | `lidar_link` (launch override) |
| publish frequency | `10.009 Hz` final average; observed intervals `0.098..0.101 s` |
| angle_min / angle_max | `-3.141592741 / +3.141592741 rad` |
| angle_increment | `0.008738784 rad` (about 0.501 degrees) |
| samples/scan | `720` |
| range_min / range_max | `0.050000001 m / 16.0 m` |
| scan_time | approximately `0.0997 s` |
| time_increment | approximately `0.0001387 s` |
| intensities | `720` values |
| invalid returns | positive infinity; 279/720 in one isolated snapshot |
| NaNs | `0` in the captured scan |
| finite returns | `441/720` in that snapshot |
| publisher QoS | reliable, volatile; depth reported as unknown by ROS graph introspection |
| time source | system/wall time (`use_sim_time` not set; no `/clock`) |

The header timestamp was nonzero and successive arrivals proved advancing scan
data. `use_sim_time` was `False` and no `/clock` was present in the isolated
hardware graph. Publisher QoS was reliable/volatile; the Control Panel adapter
subscribed best-effort/volatile, which is compatible with both source modes.

### Launch command and stable contract

```bash
cd ~/tennis-robot
source /opt/ros/jazzy/setup.bash
source ros2_ws/install_jazzy/setup.bash
ros2 launch tennis_robot lidar_hardware.launch.py
```

The default serial device is:

```text
/dev/serial/by-id/usb-Silicon_Labs_CP2102N_USB_to_UART_Bridge_Controller_3c21860b3b70f01184b98a301045c30f-if00-port0
```

The canonical ROS interface is `/scan`, `sensor_msgs/msg/LaserScan`, frame
`lidar_link`, using system time. The config is
`config/hardware_lidar.yaml`; the launch explicitly remaps the driver's relative
`scan` output to `/scan` and starts the existing `sensor_snapshot_node`.

### Clean start/stop evidence

Repeated launches reached health `OK`. During the assisted office runs, the
unmodified pinned upstream exit path stopped the motor but exceeded launch's
default five-second SIGINT grace period, causing launch to escalate to SIGTERM.
No process or stale publisher remained, but the escalation did not satisfy the
strict clean-stop gate.

Source inspection showed that the successful upstream path did not release the
SDK driver or caller-owned channel. The repository patch adds that cleanup, and
the LiDAR process receives a node-specific ten-second `sigterm_timeout` because
native SDK cleanup consistently takes about 6--7 seconds. After rebuilding on
the Pi, two consecutive `Ctrl-C` runs stopped the motor and all three launch
processes (`sllidar_node`, temporary TF publisher, and sensor snapshot node)
without an error, SIGTERM escalation, or forced kill. After each run, resetting
ROS CLI discovery made `ros2 topic info /scan` return `Unknown topic`, and
process inspection found no `sllidar_node` or hardware launch process. The
Control Panel changed from `LIVE` to `STALE` and continued aging the last
message after shutdown.

## L4 — Hardware versus simulation contract classification

The allowed classifications are: **interface-compatible** (consumers accept the
difference as part of `LaserScan`), **normalized** (the repository launch/config
deliberately presents the same contract), and **future hardware-specific**
(requires measured installation/court evidence and is not invented here).

| Property | Existing simulation | Physical C1 | Classification |
| --- | --- | --- | --- |
| message type | `sensor_msgs/msg/LaserScan` | same | interface-compatible (identical) |
| source topic | Gazebo `/gz/lidar` | driver-relative `scan` | normalized to canonical `/scan` at each bridge/launch boundary |
| frame | `lidar_link` | driver configured `lidar_link` | normalized (identical downstream) |
| angle limits | `-pi .. +pi` | `-pi .. +pi` | interface-compatible (identical) |
| angle increment | `0.012591554 rad` archived runtime | `0.008738784 rad` | interface-compatible; dynamic arrays/angles |
| samples/scan | `500` | `720` | interface-compatible; no fixed-count consumer contract |
| range limits | `0.15 .. 12.0 m` | `0.05 .. 16.0 m` | interface-compatible sensor characteristics |
| rate | `31.25 Hz` configured, not remeasured | `10.009 Hz` observed | interface-compatible; no numerical equality required |
| `scan_time` | `0`, set by Jazzy bridge conversion | about `0.0997 s` | interface-compatible optional timing detail |
| `time_increment` | `0`, set by Jazzy bridge conversion | about `0.0001387 s` | interface-compatible optional timing detail |
| timestamps | Gazebo simulation clock | Pi system/wall time | normalized by runtime `use_sim_time` policy (`false` in hardware) |
| QoS | default reliable/volatile bridge publisher | reliable/volatile driver publisher | interface-compatible (identical publisher policies) |
| invalid samples | Gazebo values copied by bridge; UI snapshot records nonfinite values as `null` | `+Inf` observed; UI records nonfinite values as `null` | normalized only in diagnostics JSON; canonical ROS message remains untouched |
| intensities | optional array copied by bridge | 720 device-specific values | interface-compatible optional field |
| noise/accuracy | configured Gaussian simulation noise | physical optics/environment | future hardware-specific court/outdoor characterization |
| base-to-LiDAR extrinsic | fixed simulated URDF geometry | temporary identity bench TF only | future hardware-specific measured mounting transform |

No numerical adapter is justified. The canonical ROS message remains unmodified;
only topic, frame parameter, and clock mode are normalized.

## L5 — TF result

For bench validation, the launch defaults to an explicitly named
`temporary_lidar_bench_tf` publisher with identity transform:

```text
base_link -> lidar_link
translation = (0, 0, 0) m
rotation quaternion = (0, 0, 0, 1)
```

`tf2_echo base_link lidar_link` resolved the transform repeatedly. This proves
frame connectivity only. It is **not** final extrinsic calibration. Disable it
with `publish_temporary_bench_tf:=false` once the final physical mount has been
measured and the robot description publishes that transform.

## L6 — Control Panel diagnostics

`sensor_snapshot_node` now derives canonical metadata from any
`sensor_msgs/msg/LaserScan`: arrival-rate window, wall-clock heartbeat age,
frame, sample/valid/invalid counts, angles, limits, and timing fields. The
Diagnostics page uses one pure `LidarView.derive` transformation and the existing
numeric ranges array for its polar/top-down plot. It has no simulator, driver,
model, serial-port, or hardware branch.

Live physical inspection on port 8082 showed `LIVE`, age, `lidar_link`, 10.0 Hz,
720 samples, `-180..180 deg`, 0.50 degree increment, `0.05..16.0 m`, nearest
range, and a moving polar point cloud. After driver shutdown it changed to
`STALE`. The generic Control Panel copy no longer describes the console as
simulation-only.

## L7 — Office validation

Stationary baseline: three snapshots two seconds apart each contained 720
samples and 429--436 finite returns. Stable sectors stayed within roughly
1--12 mm in their robust near/median values; isolated changes appeared where a
person or small object could have moved. Continuous publication and a stable
static room outline are confirmed.

An assisted run used a chair with a 30 cm broad wooden target across its thin
legs. The clearest controlled observations were:

- Near the initial physical forward line, a target measured at approximately
  `1.37 m` produced `1.359..1.400 m`, median `1.373 m`, over `14.5 deg`.
- After moving the target around the sensor, the corresponding broad return
  moved to `+89.9..+103.4 deg`; at an estimated `1.30 m` it measured median
  `1.313 m` over `13.5 deg`.
- Moving that same side target closer to approximately `0.80 m` moved the return
  to median `0.784 m` and increased its angular width to `23.0 deg`. A 30 cm
  target at 0.80 m nominally spans about `21.2 deg`, so both range and apparent
  width changed coherently.

These observations close the communication-level stationary, bearing-change,
near/far, and approximate-distance checks. Later verbal viewpoints around the
housing arrow were ambiguous and are deliberately not used to claim a final
angle offset or extrinsic. The temporary identity TF proves connectivity only.
Final mount geometry, marked front/left/right calibration, controlled lighting
characterization, and slow robot-motion validation are deferred to GitHub issue
`#16` after the permanent mount exists.

The side observations occurred in a brighter balcony area, but position and
lighting were not varied independently. They are therefore not a controlled
sunlight test and do not change the explicit `NOT TESTED` classification below.

## Tests and results

- Native Pi Jazzy/ARM64 build: the patched `sllidar_ros2` and updated
  `tennis_robot` package passed; upstream SDK warnings only. The tested patched
  source matched repository SHA-256
  `133df72431aec2bec0f450a7fbf43780f47a1aa1539b60c1b694c4a461d82dd6`.
- Pi focused tests: 14 passed, 1 skipped (Node.js-only UI transform test skipped
  on the Pi when Node is unavailable).
- Development-host focused tests: 15 passed, covering launch/config parsing,
  dependency pin, probe protocol, metadata/liveness, and UI transformation.
- JavaScript syntax checks and `git diff --check` pass.
- After merging the Field Wi-Fi mainline change, the combined focused set is 41
  passing tests. Live lifecycle, TF, QoS/rate, system time, Control Panel
  LIVE/STALE, clean SIGINT shutdown, and stale-publisher checks pass.

## Files changed

- `.gitignore`
- `ros2_ws/lidar.repos`
- `ros2_ws/patches/sllidar_ros2-clean-shutdown.patch`
- `scripts/import_lidar_dependencies.sh`
- `scripts/setup_pi.sh`
- `scripts/probe_slamtec_lidar.py`
- `ros2_ws/src/tennis_robot/package.xml`
- `ros2_ws/src/tennis_robot/config/hardware_lidar.yaml`
- `ros2_ws/src/tennis_robot/launch/lidar_hardware.launch.py`
- `ros2_ws/src/tennis_robot/launch/real_sensors.launch.py` (LiDAR portion only;
  now reuses the same config and stable default path)
- `ros2_ws/src/tennis_robot/tennis_robot/lidar_preview.py`
- `ros2_ws/src/tennis_robot/tennis_robot/sensor_snapshot_node.py`
- `scripts/control_panel.html`
- `scripts/control_panel/app.js`
- `scripts/control_panel/lidar_view.js`
- `scripts/control_panel/views/sensors.html`
- `tests/test_probe_slamtec_lidar.py`
- `tests/test_hardware_lidar_config.py`
- `tests/test_lidar_preview.py`
- `tests/test_lidar_view_js.py`
- this document

No collection planner, executor, controller behaviour, SLAM, or Nav2 tuning file
was changed.

## Explicitly NOT TESTED

- outdoor sunlight;
- court/fence/net detection;
- court-scale SLAM/localization;
- navigation;
- obstacle avoidance while driving.

## Remaining mounting/court-only work

- measure and publish the final physical `base_link -> lidar_link` extrinsic;
- repeat range/visibility characterization outdoors and around court surfaces,
  fence, and net;
- only in a later milestone, validate/tune SLAM, localization, navigation, and
  driven obstacle avoidance.

## Current milestone classification

`LIDAR_HARDWARE_INTERFACE_READY`

Reason: repository reproducibility, native ARM64 build, canonical `/scan`,
system time, frame connectivity, simulation-contract comparison, source-agnostic
Control Panel diagnostics, stationary scans, object bearing/range movement,
approximate physical distances, clean shutdown, and stale-publisher gates pass.
This classification does not include final mounting/extrinsic calibration,
controlled lighting, robot-motion validation, outdoor/court sensing, SLAM,
localization, Nav2, or driven obstacle avoidance.

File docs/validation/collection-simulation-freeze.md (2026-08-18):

# Collection subsystem — simulation freeze and hardware handoff baseline

**Status:** `COLLECTION_SIMULATION_FROZEN_FOR_HARDWARE_HANDOFF`
**Frozen at:** Phase 21 validation, 2026-08-18
**Evidence:** debug log entries #57–#86 in
[`docs/collection-route/collection-route-debug-log-el.md`](../collection-route/collection-route-debug-log-el.md)

This document is the answer to five questions a future session will ask:
what was proven in simulation, what is still unknown, which values are production
contracts, which measurements must be repeated on hardware, and what evidence is
required before reopening a frozen decision.

A guiding principle for the whole document:

> A different physical calibration does **not** reopen the architecture.
> A violated architectural invariant does.

---

## 1. What is frozen

| Subsystem | Classification | Note |
| --- | --- | --- |
| Collection scan (360°, coverage fraction) | `FROZEN_ARCHITECTURE` | `scan.required_coverage_fraction 0.6` is `SIMULATION_CALIBRATION_ONLY` (distributed RGB/depth slop, #34) |
| Ball snapshot / planning input | `FROZEN_ARCHITECTURE` | Immutable frozen snapshot per run; positions never rewritten mid-route |
| Route planner (bounded anytime pass router) | `FROZEN_ARCHITECTURE` | Coverage-first lexicographic objective, exact dominance, budget-monotonic |
| Passes and connectors | `FROZEN_ARCHITECTURE` | Pass/corridor is the search primitive; clustering only orders exploration |
| Execution plan (segments, crossings, progress) | `FROZEN_ARCHITECTURE` | Frozen at execution start; never mutated by the executor |
| Map-frame execution | `FROZEN_ARCHITECTURE` | See §4 — the single most important correction of this campaign |
| Tracking core mathematics | `FROZEN_ARCHITECTURE` | ROS-free, frame-agnostic, self-consistency verified to 7×10⁻¹⁸ m |
| Frame contract at the ROS boundary | `FROZEN_ARCHITECTURE` | Mismatched/unnamed frames throw, never compare |
| Collection crossing contract | `FROZEN_ARCHITECTURE` | Capture-grade geometry required at the ball |
| Capture heading requirement | `FROZEN_PRODUCTION_DEFAULT` | `0.15 rad`, unchanged all campaign |
| Trajectory tube (inner controller gate) | `FROZEN_PRODUCTION_DEFAULT` | `0.20 m`, recalibrated in Phase 14 against the true map-frame error |
| Progress projection | `FROZEN_ARCHITECTURE` | Forward-only accepted progress; kinematically bounded regression evidence |
| Re-anchoring handling | `FROZEN_ARCHITECTURE` | One-update tube deferral, bounded by construction |
| Confirmation attribution | `FROZEN_ARCHITECTURE` | Authoritative runtime event, persisted verbatim; no offline heuristic |
| Follow-up scan/replan | `FROZEN_ARCHITECTURE` | Phase 20B eligibility, §6 |
| Run budget | `FROZEN_PRODUCTION_DEFAULT` | `follow_up.max_total_runs = 2` |
| Audit / trace / evaluator pipeline | `FROZEN_ARCHITECTURE` | One audit + one trace per executed route, paired by `plan_id` |
| Wheel-odometry translation scale | `OPEN_FOR_HARDWARE_CALIBRATION` | No Gazebo coefficient is transferable (#82) |
| Localization correction magnitude | `KNOWN_LIMITATION` | 0.24–0.37 m erroneous jumps remain (#79) |
| Collector ingestion rate | `KNOWN_LIMITATION` | ~77% given presentation (#71); a measurement, not a specification |

Nothing in this table is called *solved* merely because simulation tolerated it.

---

## 2. Canonical runtime

**Native Ubuntu 24.04 + ROS 2 Jazzy + native Gazebo/GPU, launched by
`./run_native.sh`.** Docker/Humble is obsolete: its Nav2 parameters carry Jazzy
plugin names, so `planner_server` never configures and every route hangs before
moving (#65). Do not add Humble compatibility or distro-aware Nav2 configuration.

### Operational preflight (learned the hard way, #69 and #86)

Before every measured run:

1. terminate the full process set — `install_jazzy`, `twist_mux`, `nav2_*`,
   `slam_toolbox`, `gz sim`, and the project nodes;
2. verify no stale process survives;
3. verify **exactly one** `/clock` publisher (four publishers caused
   "Detected jump back in time", which broke TF and every route, #69);
4. verify no backward-time events in the stack log;
5. verify Nav2 lifecycle nodes `active [3]`;
6. verify a valid `map → base_footprint` transform;
7. remove **only project-owned** stale `/dev/shm/fastrtps_*` resources — 355 had
   accumulated by the end of Phase 20B and `planner_server` stopped starting
   (#86); after clearing them, six of six missions came up first time;
8. never teleport the robot after localization starts.

If Nav2 does not become healthy, the run is invalid. Do not debug collection
behaviour in a degraded environment.

---
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

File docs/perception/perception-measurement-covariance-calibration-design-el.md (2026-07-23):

# Technical Design: perception measurement covariance calibration

> Συμπληρώνει το ενεργό
> [specification](perception-measurement-covariance-calibration-rules-el.md).

## Public ROS schema

`BallDetection.msg` προσθέτει:

```text
builtin_interfaces/Time matched_depth_stamp
float64[9] position_covariance  # XYZ, row-major 3×3, m², optical frame
```

`BallDetectionArray.msg` προσθέτει:

```text
bool spatial_targets_healthy
string spatial_targets_health_reason
```

Το `header.stamp` είναι RGB acquisition timestamp. Επιτρεπτά health reasons
είναι `healthy`, `calibration_missing`, `calibration_invalid`,
`calibration_out_of_domain` και `depth_quality_insufficient`.

## Pure producer model boundary

Νέο pure module `perception_covariance_calibration.py` ορίζει:

- immutable `CalibrationArtifact` parser/validator,
- `DepthQualityMetrics`,
- `CovarianceModel` interface,
- typed result: covariance ή explicit rejection reason.

Η πρώτη supported model ID είναι `range_depth_quality_diagonal_v1`. Τα artifact
parameters ορίζουν τις τρεις calibrated axis-variance functions. Η μοντελοποίηση
είναι deterministic: variance κάθε axis είναι monotonic non-decreasing ως προς
range και monotonic non-increasing ως προς depth quality. Εκτός declared domain
επιστρέφει rejection και όχι extrapolation.

Το artifact είναι strict JSON object με:
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

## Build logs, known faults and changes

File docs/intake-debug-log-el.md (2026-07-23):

# Intake roller/lip debugging — log

Σκοπός: αρχείο-καταγραφή για κάθε ενέργεια/διόρθωση γύρω από το intake
(roller, lip, channel, debug camera) ώστε να μην ξαναγυρνάμε στον ίδιο κύκλο.
Νέα εγγραφή ανά αλλαγή: τι δοκιμάστηκε, τι αποτέλεσμα είχε, τι επόμενο βήμα.

## 2026-07-08

### 1. Root cause: channel geometry δεν ακολουθούσε τα intake offsets
- **Βρέθηκε**: `scripts/generate_curved_scoop_mesh.py` και το `_patch_sdf_contacts`
  στο `scripts/generate_robot_urdf.py` είχαν hardcoded `ROLLER_X=0.615`,
  `ROLLER_Z=0.112` — αγνοούσαν τα `INTAKE_ROLLER_X_OFFSET_M` /
  `INTAKE_ROLLER_Z_OFFSET_M` που μετακινούν τον πραγματικό roller μέσω
  `tennis_robot.urdf.xacro`. Επαληθεύτηκε αριθμητικά μέσα από το γεννημένο
  SDF: πριν τη διόρθωση, roller στο `x=0.615,z=0.107` αλλά το channel arc
  center στο `x=0.600,z=0.112` (mismatch 15mm X / 5mm Z).
- **Fix**: και τα δύο scripts διαβάζουν τώρα τα ίδια env vars και μετατοπίζουν
  το channel/mesh μαζί με τον roller.
- **Επαλήθευση**: μετά τη διόρθωση, roller και channel center ταυτίζονται
  ακριβώς (`x=0.615,z=0.107` και τα δύο) στο γεννημένο SDF.
- **Status**: ✅ εφαρμόστηκε, επαληθεύτηκε αριθμητικά.

### 2. Πρώτο `collect_one` test μετά τη διόρθωση
- Στάλθηκε νέα εντολή collect_one (`runtime/robot_command.json`, sequence 60).
- Screenshot από τον χρήστη: μπάλα ακριβώς στο άκρο του intake, στη φάση
  `capture`.
- Λίγο μετά: `collector_state` γύρισε σε `approach`, `collection_count: 0` —
  η προσπάθεια capture ΔΕΝ πέτυχε ακόμα, παρά τη διόρθωση γεωμετρίας.
- **Status**: ⚠️ ανοιχτό — χρειάζεται οπτική/telemetry επιβεβαίωση γιατί
  αποτυγχάνει ακόμα το capture.

### 3. Debug camera (sim-only) — προσπάθεια οπτικής επιβεβαίωσης
- Προστέθηκε `intake_debug_camera.urdf.xacro`: κάμερα mounted στο
  `base_link` (x=0.45, z=-0.03 rel. δηλ. ~15mm πάνω από το έδαφος), pitch
  -0.51 rad (~29° πάνω), gated πίσω από `sim_mode` (μόνο sim). Bridge added
  σε `gazebo/bridge_config.yaml` (`/gz/intake_debug_camera` →
  `/camera/intake_debug/image_raw`).
- **Attempt 1**: πρώτο frame εντελώς μαύρο (min=max=mean=0). Front/oak-d
  camera δούλευε κανονικά (δοκιμάστηκε για σύγκριση) — άρα δεν είναι γενικό
  πρόβλημα rendering pipeline.
- **Υπόθεση A**: η κάμερα κοιτάζει τη σκιασμένη κάτω πλευρά του σασί (ο
  ήλιος της σκηνής δεν φτάνει εκεί) → **Fix**: προστέθηκε spot light
  (`intake_debug_camera_link_spotlight`) στο ίδιο link, ίδια θέση/κατεύθυνση
  με την κάμερα. **Αποτέλεσμα: ΑΚΟΜΑ μαύρο** (frame3.png, min=max=mean=0).
- **Υπόθεση B**: το `<direction>` του spot light στο gz-sim ΔΕΝ περιστρέφεται
  μαζί με το `<pose>` του (γνωστό quirk) — δηλ. direction="1 0 0" σήμαινε
  οριζόντια δέσμη, όχι προς τα πάνω. **Fix**: explicit world-frame direction
  vector (`0.8736 0 0.4870`, υπολογισμένο ώστε να δείχνει ακριβώς στον
  roller target). **Αποτέλεσμα: ΑΚΟΜΑ μαύρο** (frame4.png, min=max=mean=0).
- **Status**: ❌ ανοιχτό μετά από 2 αποτυχημένες υποθέσεις/διορθώσεις.
  Frame παραμένει *ακριβώς* μηδέν (όχι απλά σκοτεινό) σε κάθε προσπάθεια —
  ένδειξη ότι μπορεί να μην είναι θέμα φωτισμού αλλά κάτι πιο δομικό (π.χ.
  τίποτα μέσα στο frustum πριν το far clip, near-clip clipping μέσα σε στερεό
  σώμα, ή κάποιο πρόβλημα στο ίδιο sensor config).
- **Attempt 3 (depth diagnostic)**: προστέθηκε companion depth camera στο ίδιο
  link/γωνία (`/gz/intake_debug_depth` → `/camera/intake_debug/depth`). Το
  depth δεν εξαρτάται από φωτισμό. **Αποτέλεσμα (καθοριστικό)**: και τα 307200
  pixels διάβασαν **0.080–0.087 m** — δηλαδή ένα επίπεδο στερεό ~8cm μπροστά
  γεμίζει ΟΛΟ το κάδρο. Άρα το μαύρο RGB **ΔΕΝ ήταν ποτέ θέμα φωτισμού** — η
  κάμερα ήταν **μπλοκαρισμένη**, κοιτούσε μέσα στη γεωμετρία (πιθανότατα την
  κάτω/πίσω πλευρά του ίδιου του scoop channel) αντί για τον roller στα ~0.19m.
  → Τα δύο light fixes (#3 attempts 1-2) ήταν **λάθος διάγνωση**· δεν χρειάζονταν.
- **Fix (position + light)**:
  - Μετακίνηση κάμερας από head-on underside (`0.45 0 -0.03`) σε **πλάι-κάτω**
    (`base_link 0.5 0.13 -0.02`, ~25mm πάνω από έδαφος, μόλις μέσα από το
    funnel cheek στο y=0.145), με διαγώνια στόχευση inward-up-forward
    (`rpy 0 -0.441 -0.847`) ώστε η γραμμή θέασης να μπαίνει από το πλάι του
    channel όπου δεν υπάρχει εμπόδιο. Απόσταση στον roller 0.192m
    (υπολογισμένη, γραμμή θέασης ελεγμένη ότι δεν τέμνει cheek/chassis).
  - Το spot light έγινε **point light** (omnidirectional) — παρακάμπτει
    τελείως το gz-sim `<direction>` world-frame quirk.
- **Αποτέλεσμα (restart #8)**: ✅ **ΔΟΥΛΕΥΕΙ**. depth τώρα δομημένο
  (0.034–0.218m, 258802/307200 finite, median 0.099) — καθαρή θέαση, όχι
  μπλοκάρισμα. RGB (frame6.png) φωτισμένο (min 0 / max 255 / mean 58). Η
  εικόνα δείχνει καθαρά τον roller (σκούρος κύλινδρος αριστερά-κέντρο) + μια
  κίτρινη μπάλα (πάνω-αριστερά) + φράχτη στο φόντο.
- **Status**: ✅ camera λειτουργεί. **Εκκρεμεί βελτίωση framing**: ο roller
  γεμίζει το κάδρο (η κάμερα είναι ~4cm από το κοντινό άκρο του roller στο
  y=0.09), η μπάλα είναι στη γωνία, το δεξί μισό μαύρο. Για καθαρό "nip
  contact" shot θέλει είτε ευρύτερο FOV (1.0→~1.5) είτε λίγο πιο πίσω/έξω
  τραβηγμένη κάμερα ώστε να κεντραριστεί το σημείο επαφής ball-roller-lip.

### 4. Παράπλευρο fix: RViz markers ποτέ δεν εμφανίζονταν (ξεχωριστό, real bug)
- **Βρέθηκε**: `gazebo_extras_node.py`'s `_on_pose_info` έθετε `self._robot_pose`
  μόνο όταν `child_frame_id.split("::")[-1] == "tennis_robot"` — αλλά το
  `/gz/pose_info` bridge δίνει `child_frame_id=''` για ΚΑΘΕ transform σε αυτή
  την έκδοση του Gazebo (επιβεβαιώθηκε ήδη νωρίτερα ίδια session). Άρα
  `self._robot_pose` έμενε πάντα `None`, και οι publishers
  `/sim/roller_contact_markers` + `/sim/ball_markers` έκαναν σιωπηλά no-op —
  το `RollerContacts` display στο RViz (ήδη υπήρχε στο config) ποτέ δεν
  έδειχνε τίποτα.
- **Fix**: robot pose τώρα έρχεται από `/odom` (nav_msgs/Odometry) αντί για
  το σπασμένο pose_info name-matching.
- **Status**: ✅ εφαρμόστηκε. **Δεν έχει επαληθευτεί ακόμα** ότι τα markers
  όντως εμφανίζονται τώρα στο RViz (δεν έγινε ακόμα δοκιμή με πραγματική
  επαφή μετά τη διόρθωση).

### 5. RViz config
- Προστέθηκε `Image` display για `/camera/intake_debug/image_raw` στο
  `docker/ros2/tennis_robot.rviz` (`IntakeDebugCamera`). Επιβεβαιώθηκε ότι
  εμφανίζεται στο panel (screenshot χρήστη) — αλλά δείχνει μαύρο γιατί η ίδια
  η κάμερα ακόμα δεν βγάζει εικόνα (βλ. #3).

### 6. Framing refinement της debug camera
- **Πρόβλημα**: στο frame6.png ο roller γεμίζει το κάδρο (κάμερα ~4cm από το
  κοντινό του άκρο), η μπάλα πέφτει στη γωνία, το δεξί μισό μαύρο — δεν
  φαίνεται καθαρά το σημείο επαφής ball/roller/lip.
- **Αλλαγή** (θέση ΔΕΝ αλλάζει — είναι επιβεβαιωμένα καθαρή):
  - FOV 1.0 → 1.5 rad (~86°) και στα δύο sensors (RGB + depth).
  - Στόχευση από roller centre (0.615,0,0.107) → **nip midpoint**
    (0.607,0,0.075): `rpy 0 -0.441 -0.847` → `0 -0.289 -0.882`
    (dist 0.176m).
- **Αποτέλεσμα (restart #9)**: ✅ frame7.png δείχνει πλήρες πλάνο: roller
  (πάνω-αριστερά), scoop channel σε σιλουέτα με το lip να ακουμπά το έδαφος,
  court + γραμμή στο φόντο, front-left τροχός. Depth 0.028–1.702m
  (δομημένο, με ορίζοντα). Το nip visible. Η κάμερα-εργαλείο είναι έτοιμη.
- **Status**: ✅ ολοκληρώθηκε.

### 7. Rosbag capture-failure test (instrumented collect_one)
- **Στόχος**: ποσοτική απάντηση στο "αγγίζει η μπάλα τον roller;" — timeline
  απόστασης μπάλας-roller + contact events + joint vel + beam + camera frames.
- **Σημείωση**: το `ros2 bag play` δεν ξανατρέχει φυσική· το test είναι
  record → offline ανάλυση.
- **Εύρημα κατά το setup**: το raw gz `/world/tennis_court/pose/info` ΕΧΕΙ
  entity names — το ros_gz bridge (Pose_V→TFMessage) είναι που τα πετάει
  (child_frame_id=''). Ground truth λοιπόν μέσω `gz topic --json-output` CLI.
- **Εύρημα #2**: μετά το restart #9 ο controller μπήκε ΜΟΝΟΣ του σε
  collect_one (το robot_command.json είχε μείνει σε collect_one) και η
  ball_02 βρέθηκε σπρωγμένη από (-6.4,0) στο (-0.06,0.00) χωρίς capture —
  live αναπαραγωγή του συμπτώματος. → Πριν από restart τεστ, γράφε idle.
- **Εργαλεία** (scripts/sim_debug/): `log_gz_poses.py` (ground-truth
  JSONL ~20Hz), `analyze_collect_bag.py` (bag+JSONL → closest approach,
  contact count, camera frames γύρω από το κρίσιμο σημείο).
- **Bag topics**: /gz/roller_contact_0, /joint_states,
  /collector/intake_beam_broken, /odom, /cmd_vel, /sim/roller_contact,
  /camera/intake_debug/image_raw.
- **Αποτελέσματα (run: collect_test1, bags στο runtime/bags/)**:
  - Ροή: idle → approach (19s) → capture (6s) → reverse_clear, **0 collected**.
  - **Η μπάλα ΑΓΓΙΖΕΙ τον roller**: 496 ball-contact messages στο
    `/gz/roller_contact_0` επί **2.24s συνεχόμενα**. Η υπόθεση "δεν κάνει
    επαφή" **καταρρίπτεται** από τα δεδομένα.
  - Closest approach: κέντρο-κέντρο 69mm → surface gap **-9mm**
    (διείσδυση — συμπίεση από τον solver). Ball κεντραρισμένη τέλεια
    (lateral **0mm**), κέντρο +25mm μπροστά από τον άξονα roller, στο έδαφος
    (z=43mm = rest height).
  - Beam broken 73 δείγματα (η μπάλα στο nip), roller |vel| max 30 rad/s
    (γύριζε κανονικά).
  - Frames: η μπάλα κάθεται στο lip, πιεσμένη στο μπροστινό-κάτω τεταρτημόριο
    του roller, και μένει εκεί — **σφηνωμένη στο λαιμό**, μέχρι που ο robot
    κάνει reverse_clear.
- **Νέα διάγνωση (root cause candidate): ο λαιμός είναι στενότερος από τη
  μπάλα για rigid bodies.**
  - Κάτω διάκενο roller-έδαφος: 107-45 = **62mm** < 66mm μπάλα (το probe το
    τύπωνε ήδη: "ball fit margin=-4.0mm").
  - Το tuning `INTAKE_ROLLER_Z_OFFSET_M=-0.005` ("χαμήλωσε τον roller") το
    προκάλεσε: στο baseline z=112 το διάκενο ήταν 67mm (+1mm ελεύθερο).
  - Κανάλι-roller: 108-45 = 63mm σχεδιαστικά ("3mm nominal interference,
    μοντελοποιεί συμπίεση αφρού") — αλλά o DART με rigid μπάλα ΔΕΝ συμπιέζει:
    η μπάλα απλά δεν χωράει, σφηνώνει (γι' αυτό το 9mm penetration spike), ο
    solver τη σπρώχνει έξω.
  - Το lip raise +2mm στενεύει την είσοδο επιπλέον.
- **Status**: ✅ διάγνωση ολοκληρώθηκε. Επόμενο: A/B rerun με ανοιχτό λαιμό.

### 8. A/B test: άνοιγμα λαιμού (undo roller lowering)
- **Αλλαγή** (ΜΙΑ μεταβλητή): `INTAKE_ROLLER_Z_OFFSET_M=-0.005` → `0.0`
  (roller πίσω στο baseline z=112 → κάτω διάκενο 67mm, +1mm ελεύθερο για
  66mm μπάλα). Κρατάμε `INTAKE_ROLLER_X_OFFSET_M=0.015` και
  `INTAKE_LIP_RAISE_M=0.002` ως έχουν. Το κανάλι ακολουθεί αυτόματα τον
  roller (fix #1), άρα το arc μένει ομόκεντρο.
- **Διαδικασία**: ίδιο instrumented test (collect_test2) για άμεση σύγκριση
  με collect_test1.
- **Κριτήριο επιτυχίας**: μπάλα περνάει το nip (beam → basket beams,
  balls_collected>0), ή τουλάχιστον σαφώς βαθύτερη πρόοδος στο κανάλι αντί
  για static jam 2.2s + reverse_clear.
- **Αποτελέσματα (collect_test2)**: πάλι 0 collected, αλλά με ΑΝΤΙΘΕΤΟ
  μηχανισμό αποτυχίας:
  - test1 (z=-5mm, διάκενο 62mm): μπάλα σταμάτησε +25mm ΜΠΡΟΣΤΑ από τον
    άξονα, 496 contacts επί 2.2s → **σφηνωμένη** στο nip.
  - test2 (z=0, διάκενο 67mm): μπάλα έφτασε +5mm από τον άξονα (σχεδόν από
    κάτω του), beam 57 hits, **0 contacts** — πέρασε ΚΑΤΩ από τον roller με
    ~1mm αέρα **χωρίς να τον αγγίξει ποτέ** → μηδενική πρόσφυση, ο roller
    γύριζε στον αέρα.
  - Σημ.: το court surface είναι ~10mm πάνω από το world z=0 (η μπάλα
    "rest" z=43mm = 33mm ακτίνα + 10mm court) — τα per-frame "surface gap"
    του analyzer έχουν αυτό το offset· τα contact counts του sensor είναι η
    αλήθεια.
- **Συμπέρασμα (διπλό μπλόκο, και τα δύο αποδεδειγμένα)**:
  1. **Grip**: με rigid σώματα, interference = σφήνωμα (test1) και clearance
     = καμία πρόσφυση (test2). Δεν υπάρχει ενδιάμεσο σημείο για σταθερό
     fixed-axis rigid roller — χρειάζεται ΕΝΔΟΤΙΚΟΤΗΤΑ (όπως ο πραγματικός
     αφρός): είτε spring-suspended roller (prismatic joint + spring —
     υποστηρίζεται από DART) είτε soft-contact params (αβέβαιη υποστήριξη
     στο dartsim).
  2. **Πέρασμα**: ακόμα κι αν ο roller έπιανε τη μπάλα, το κανάλι-arc έχει
     διάκενο 108-45=63mm < 66mm μπάλα σε ΟΛΟ το μήκος του ("3mm nominal
     interference" by design) — η μπάλα δεν χωράει πουθενά στη διαδρομή.
     CHANNEL_R πρέπει ≥ 113mm (45+66+2mm slack).
- **Status**: ✅ διάγνωση πλήρης. Επόμενο: fix και των δύο + rerun.

### 9. Fix: spring-suspended roller + κανάλι 113mm (απόφαση χρήστη: μαζί)
- **Αλλαγή A (πέρασμα)**: CHANNEL_R 0.108 → **0.113** και στα δύο σημεία
  (generate_curved_scoop_mesh.py + _patch_sdf_contacts) → διάκενο
  roller-καναλιού 68mm, μπάλα 66mm περνά με 2mm slack.
- **Αλλαγή B (grip)**: ο roller κρεμιέται σε παθητικό prismatic z-joint
  (carriage) με ελατήριο (SDF `<dynamics><spring_stiffness>` — patch στο
  SDF αφού το URDF δεν έχει springs). Rest position με ~8mm interference
  (`INTAKE_ROLLER_Z_OFFSET_M=-0.009` → κέντρο 103mm, κάτω άκρο 58mm για
  μπάλα-top 66mm), ελατήριο k≈300 N/m ώστε η μπάλα να το σηκώνει
  συμπιέζοντας «αφρό» και να δέχεται συνεχή δύναμη πρόσφυσης χωρίς σφήνωμα.
  Travel: 0..+15mm (κάτω stop στο rest, δεν πέφτει από βαρύτητα).
- **Προσοχή**: το contact sensor δείχνει σε συγκεκριμένο lumped collision
  name — με τη νέα δομή (carriage) το όνομα μπορεί να αλλάξει· το patch
  γίνεται δυναμικό (βρίσκει το πραγματικό roller_col collision στο SDF)
  αλλιώς θα μετράμε σιωπηλά 0 contacts.
- **Σφάλμα διαδικασίας (διορθώθηκε)**: το πρώτο collect_test3 δεν έστειλε
  ποτέ collect_one — το runtime/robot_command.json ήταν root-owned (ο
  controller στο container το ξαναγράφει ως root) και το host-side write
  απέτυχε με EACCES. Ο orchestrator στέλνει πλέον την εντολή ΜΕΣΑ από το
  container. Μάθημα: εντολές στο robot_command.json πάντα μέσω
  `docker compose exec`.
- **Αποτελέσματα (collect_test3, spring+113)**: 0 collected ΑΛΛΑ τεράστια
  πρόοδος — **το grip δουλεύει**:
  - t=23.4s: ο roller ΑΡΠΑΞΕ τη μπάλα: fwd +30 → **-64mm** (πίσω από τον
    άξονα), z 43→65mm. Το ελατήριο υποχώρησε (~11mm) όπως σχεδιάστηκε.
  - t=24-35s: η μπάλα ΣΤΑΣΙΜΗ στο fwd≈-43mm, z=46 επί 11s — μέσα στο
    κανάλι, contact μόνο σποραδικό (193 msgs/13s ≈ 15%).
  - t=36s: reverse_clear την άφησε πίσω στο έδαφος.
- **Διάγνωση νεκρής ζώνης**: το z=-9mm κατέβασε το τόξο ώστε πίσω από τον
  άξονα να πέφτει κάτω από το floor clamp (3mm) → επίπεδη τσέπη με κενό
  10+mm από τον roller. Η μπάλα ισορροπεί στο dx=-43 με το κέντρο της
  1.6mm έξω από το grip radius (79.6 vs 78mm) — ο roller γυρνά από πάνω
  της χωρίς επαφή, το τόξο την ξανακυλά πίσω.
- **Refinement (test4)**: z offset -0.009 → **-0.002** (1mm entry bite,
  4mm under-axis squeeze) και CHANNEL_R 0.113 → **0.109** (το τόξο κρατά
  τη μπάλα κολλημένη στον roller πίσω από τον άξονα· max coast gap ~1mm).
  Το ελατήριο μετατρέπει το interference σε grip force αντί για σφήνωμα.
- **Αποτελέσματα (collect_test4, z=-0.002 / R=0.109)**: 0 collected, αλλά
  το τρίτο και βαθύτερο στάδιο μέχρι τώρα:
  - Grip άμεσο και **συνεχής επαφή** (2561 msgs επί 14.4s, vs 193 σποραδικά
    στο test3) — το refinement του τόξου δούλεψε.
  - Η μπάλα **σκαρφάλωσε όλο το τόξο**: fwd +13→-75mm, z 43→**113mm**
    (ύψος άξονα) σε 0.8s.
  - Στάσιμη στο (fwd -75, z 112) επί 13s: σφηνωμένη ανάμεσα σε roller και
    πίσω τοίχο, **γυρνούσε επιτόπου σαν ρουλεμάν** — roller μ=2.5 της δίνει
    spin, τοίχος μ=0.15 δεν το μετατρέπει σε αναρρίχηση (0.15×N ≈
    0.15-0.45N < βάρος 0.57N).

### 10. Fix: τριβή καναλιού 0.15 → 0.8 (test5)
- Το 0.15 ήταν σχεδίαση της rigid εποχής ("μη καρφώνει τη μπάλα") — με το
  sprung roller το pinch είναι πλέον feature.
- **Αποτέλεσμα (collect_test5)**: ΙΔΙΟ stall (fwd -75, z 112, 13s).
  Επαληθεύτηκε ότι το μ=0.8 ΗΤΑΝ live στο SDF — το fix μπήκε, απλά δεν
  έφτανε.

### 11. Διορθωμένο ισοζύγιο + fix: μ=1.4 και spring k=500 (test6)
- **Ποσοτικό ισοζύγιο στο stall point** (fwd -75, z 103, squeeze 2.6mm):
  - Κάτω: βάρος 0.57N + κάθετη συνιστώσα roller-normal 0.08N = 0.65N.
  - Πάνω (τριβή τοίχου, μπάλα-ρουλεμάν): μ_wall × N, με N = k×lift =
    300×2.6mm ≈ 0.78N.
  - μ=0.15 → 0.12N (κολλημένη ✓ ταιριάζει με test4)
  - μ=0.8 → 0.62N vs 0.65N (ΟΡΙΑΚΑ κολλημένη ✓ ταιριάζει με test5!)
  - Το μοντέλο προβλέπει σωστά και τα δύο αποτελέσματα.
- **Fix**: μ_wall 0.8→**1.4** (λάστιχο, όπως οι πραγματικοί συλλέκτες) ΚΑΙ
  spring k 300→**500** N/m → ανοδική ≈ 1.4×1.3 = 1.8N vs 0.65N (2.7×
  περιθώριο). Δύο αλλαγές μαζί σκόπιμα: πολλαπλασιαστικά μέλη του ίδιου
  όρου (μ×N), το ισοζύγιο είναι πλέον μετρημένο.
- **Αποτελέσματα (collect_test6b· το πρώτο test6 χάθηκε από restart-race
  των recorders — μπήκε uptime guard στον orchestrator)**: ΙΔΙΟ stall
  (fwd -75, z 113) και με μ=1.4 + k=500. Δύο διαψεύσεις → το μοντέλο
  «friction-αναρρίχηση» ήταν λάθος επίπεδο ανάλυσης.

### 12. Η πραγματική γεωμετρική αιτία του stall: νεκρή ζώνη #2 (test7)
- **Απόδειξη**: για να περάσει η μπάλα πρέπει το κέντρο της να φτάσει
  ~z=188 (πάνω από το χείλος τοίχου z=155). Η εμβέλεια του roller
  (78mm από άξονα) τελειώνει στο z≈130 στην τροχιά αναρρίχησης → 58mm
  ΧΩΡΙΣ καμία ώθηση. Το design υπέθετε βαλλιστική εκτόξευση, αλλά η
  quasi-static μεταφορά δίνει ~0.67 m/s → άνοδος μόνο 23mm. Καμία τριβή
  δεν γεφυρώνει 58mm κενό — γι' αυτό απέτυχαν το #10 και το #11.
- **Fix (δομικό, όπως οι πραγματικοί συλλέκτες)**: ο κατακόρυφος τοίχος
  αντικαταστάθηκε από **συνέχιση του ομόκεντρου τόξου γύρω από το πίσω
  μέρος του roller** μέχρι z=155 (guide angle έως asin((155-110)/109)≈24°).
  Με ομόκεντρο οδηγό ο roller οδηγεί τη μπάλα ΕΦΑΠΤΟΜΕΝΙΚΑ σε όλη τη
  διαδρομή (η επαφή διατηρείται by construction) και τη ρίχνει από την
  κορυφή με φορά πάνω-πίσω προς deflector/basket.
- Λεπτομέρεια: το underside του collision polygon στο guide τμήμα παίρνει
  ΑΚΤΙΝΙΚΟ offset (R+2mm) — κατακόρυφο offset θα στένευε το πέρασμα 2mm.
- Αρχεία: generate_curved_scoop_mesh.py (νέο profile με GUIDE_STEPS),
  generate_robot_urdf.py (νέο polyline top+underside).
- **Αποτελέσματα (collect_test7)**: ΙΔΙΟ stall (fwd -75, z 113, 26s) και με
  τον ομόκεντρο οδηγό. 4η διαμόρφωση με πανομοιότυπο σημείο καθηλώματος.

### 13. ΤΕΛΙΚΗ ρίζα: 1-DOF κατακόρυφη ανάρτηση ≠ ακτινική ενδοτικότητα
- **Γεωμετρική απόδειξη**: το ελατήριο κινεί τον roller μόνο κατακόρυφα,
  αλλά η μπάλα σε τροχιά γύρω του χρειάζεται ακτινική υποχώρηση ~2mm
  παντού (guide R=109 → πέρασμα 64mm < 66mm μπάλα). Απαιτούμενο vertical
  lift για 2mm ακτινικά: κάτω=2mm ✓· στο fwd -75 = √(78²-75²) =
  **21.4mm > 15mm travel** → μπλόκο ΑΚΡΙΒΩΣ εκεί που κολλάει κάθε test·
  πίσω-οριζόντια=17.7mm· πάνω από τον άξονα: αδύνατον (θα έπρεπε να
  κατέβει κάτω από το rest). Εξηγεί το πανομοιότυπο fwd=-75 των tests
  4/5/6b/7 ανεξαρτήτως τοίχου/τριβής/ελατηρίου/οδηγού.
- Ο αληθινός αφρός συμπιέζεται ΑΚΤΙΝΙΚΑ (υλική ενδοτικότητα), όχι σαν
  ανάρτηση άξονα.
- **Επόμενο fix (μεγάλο αλλά το πρώτο γεωμετρικά ικανό): paddle roller**
  — hub + 6 πτερύγια σε revolute joints με ελατήρια (SDF patch όπως το
  carriage). Κάθε πτερύγιο λυγίζει ακτινικά → πραγματική ενδοτικότητα σε
  όλη την τροχιά. Ιστορικό εύρημα: τα bridges roller_contact_0..7 και το
  σχόλιο "Real physics contacts from each intake paddle" δείχνουν ότι το
  ΑΡΧΙΚΟ design ήταν paddle wheel — η απλοποίηση σε συμπαγή κύλινδρο
  είναι που αχρήστεψε τη φυσική της σύλληψης.
- **Status**: εγκρίθηκε από χρήστη → υλοποίηση στο #14.

### 14. Υλοποίηση paddle roller (test8)
- **Δομή**: `lift_wheel_link` γίνεται hub (κύλινδρος r=25mm, το ros2_control
  joint `lift_wheel_joint` μένει ίδιο, ξανά απευθείας στο base_link) + 8
  πτερύγια (boxes 25×180×4mm) το καθένα σε δικό του revolute joint
  (±1.2 rad) με SDF-patched spring (k=0.25 N·m/rad, damping 0.02,
  reference 0). Tips στα 50mm — ελαφρώς μεγαλύτερο envelope από τον παλιό
  κύλινδρο (45), συμπιέσιμο ακτινικά έως ~hub.
- **Το κατακόρυφο carriage (#9) ΑΦΑΙΡΕΘΗΚΕ** — με ακτινική ενδοτικότητα
  ανά πτερύγιο είναι περιττό, και το travel-limit του ήταν το μπλόκο του #13.
- **Sensors**: ένα contact sensor ανά πτερύγιο → roller_contact_0..7 — τα
  8 bridges που υπήρχαν ήδη ξαναγεμίζουν όλα. Το SDF patch δένει δυναμικά
  κάθε sensor στο collision του αντίστοιχου paddle link (fail-loud αν
  λείπει κάποιο από τα 8).
- **Τριβές**: paddles μ=2.5 (λάστιχο), hub μ=0.8. Κανάλι μένει μ=1.4,
  guide R=109 (πέρασμα 59mm vs tips → τα πτερύγια λυγίζουν ~40° στο nip,
  δύναμη λαβής ~7N).
- **Αποτελέσματα (collect_test8)**: 0 collected αλλά **το paddle roller
  λύνει το radial-compliance πρόβλημα**:
  - Η μπάλα μεταφέρθηκε σε ΟΛΟ το τόξο: fwd +15→-76, z 43→**171mm** σε
    1.6s — πέρασε το μοιραίο fwd -75 (πρώτη φορά σε 8 tests) ΚΑΙ το
    guide release (155).
  - Μετά: **juggle** στην κορυφή του τροχού (fwd -66, z≈167) επί 12s — στην
    κορυφή τα πτερύγια κινούνται ΜΠΡΟΣΤΑ (φυσική του τροχού: πάνω=+x),
    οπότε δεν μπορούν να σπρώξουν τη μπάλα πίσω προς το καλάθι.
  - Σημ. ανάλυσης: το bag γράφει μόνο roller_contact_0 (1 από 8 πτερύγια)
    — στο επόμενο test προσθήκη και των 8 στο record list.
- **Εναπομένον πρόβλημα (το τελευταίο): handoff στο καλάθι.**
  - Ο υπάρχων deflector (ground z 204-266) σχεδιάστηκε για βαλλιστική
    εκτόξευση· η paddle-μεταφορά δίνει peak μόλις ~204 (οριακό άγγιγμα).
  - Γεωμετρικός περιορισμός: το πάνω μέρος του τροχού πάντα οδηγεί ΜΠΡΟΣΤΑ
    — η μπάλα πρέπει να φύγει από τον τροχό και να ταξιδέψει πίσω είτε
    βαλλιστικά είτε από στατική επιφάνεια. Επιπλέον το basket floor top
    (ground 128, front edge x=0.42) απαιτεί κέντρο μπάλας ~161 για να
    πατήσει — το guide exit δίνει 141 (το juggle έδινε 167).
  - Υποψήφιο πακέτο (test9): (α) οροφή-deflector ΠΙΣΩ-ψηλή (front-low) πάνω
    από το juggle ώστε η ανοδική-εμπρός κρούση να ανακλάται πίσω-κάτω,
    (β) επέκταση basket floor μπροστά (x→~0.50) ώστε η μπάλα που πέφτει
    πίσω από το guide sheet να προσγειώνεται σε πάτωμα και όχι στο κενό
    (x 0.42-0.50 σήμερα δεν έχει τίποτα από κάτω), (γ) πιθανό μέτριο speed
    bump για ενέργεια. Θέλει σχεδιασμό με τα juggle kinematics από το bag.
- **Status**: paddle roller ✅ λειτουργεί· handoff → #15.
- Commit checkpoint: 4cc7886 (paddle roller + εργαλεία + log).

### 15. Handoff πακέτο (test9): spin-walk ceiling + επέκταση basket floor
- **Physics insight**: στο juggle η μπάλα έχει BACKSPIN (τα πτερύγια οδηγούν
  το κάτω μέρος της μπροστά → το πάνω γυρνά πίσω). Οροφή σε επαφή από πάνω
  → η τριβή τη «περπατάει» ΠΙΣΩ κατά μήκος της οροφής (όπως μπαλάκι με
  φάλτσο κάτω από τραπέζι). Δεν χρειάζεται βαλλιστική.
- **Αλλαγή Α (deflector → spin-walk ceiling)**: από front-high (0.425,0,
  funnel 0.197, rpy -0.43) σε **front-LOW/rear-HIGH** (0.52,0,funnel 0.167,
  rpy +0.43, box 0.16×0.20×0.006). Underside στο juggle x=0.549: ground
  z≈0.192 = μέσα στη ζώνη ball-top (0.195-0.204) → συνεχής επαφή. Front
  edge (0.593, 0.172): κενό από paddle tips 15.8mm < μπάλα → μπλοκάρει
  εμπρός διαφυγή. Τριβή deflector μ=1.2 (νέο patch match στο SDF script).
- **Αλλαγή Β (basket floor forward)**: floor top 0.128 επεκτείνεται από
  x=0.42 σε **x=0.50** (box 0.54→0.62, centre 0.15→0.19) — κλείνει το κενό
  x 0.42-0.5045 όπου η μπάλα έπεφτε στο court. Έλεγχοι: 4.5mm από το guide
  sheet (μπάλα δεν χωράει να πέσει)· floor corner 116mm από άξονα > 50
  paddle sweep ✓· μπάλα πάνω στο floor εκτός εμβέλειας πτερυγίων ✓.
- **Ταχύτητα roller αμετάβλητη** (30 rad/s) — μία μεταβλητή τη φορά· το
  spin-walk δεν θέλει ενέργεια.
- **Αναμενόμενη ροή**: juggle → επαφή οροφής → spin-walk πίσω → κύλισμα
  πάνω από το guide edge (fulcrum) → πτώση στο extended floor →
  basket beams → collected=1.
- **Αποτελέσματα (collect_test9)**: 0 collected, αλλά η οροφή δουλεύει
  εν μέρει: το juggle ΕΞΑΛΕΙΦΘΗΚΕ — η μπάλα κρατιέται ΣΤΑΘΕΡΗ στο
  (fwd -66, z 161-162) επί 13s (πριν: αναπήδηση 162-171). Δεν έγινε όμως
  spin-walk προς τα πίσω.
- **Μετρημένη αιτία**: η μπάλα καρφώνεται στο όριο εμβέλειας πτερυγίων
  (dist 84mm ≈ 83mm tips+μπάλα = οριακό άγγιγμα, όχι οδήγηση). Η οριζόντια
  εμβέλεια των πτερυγίων τελειώνει στο x≈0.532 — το χείλος του guide είναι
  στο x=0.5045: **20mm κενό χωρίς καμία ώθηση** που κανένα ύψος οροφής δεν
  γεφυρώνει.
- Commit checkpoint: 73533d2 (handoff package), pushed στο origin.

### 16. Επόμενο (test10): ύψωση guide exit κάτω από το pinned spot
- **Ιδέα (μία παράμετρος)**: guide_top_z 0.155 → **0.175**. Το χείλος
  απελευθέρωσης μετακινείται εμπρός στο x=0.5275 (sinφ=(0.175-0.110)/0.109
  → φ=36.6°) — ακριβώς κάτω από το σημείο όπου η μπάλα κάθεται σταθερά
  (0.549, 0.162). Η μπάλα, πιεσμένη οροφή-πτερύγια, γέρνει πάνω από το
  χείλος (fulcrum) και πέφτει πίσω του στο extended floor (0.128) →
  basket beams.
- Αλλαγές: WALL_TOP_Z/guide_top_z και στα δύο scripts (mesh + SDF patch).
  Έλεγχος: το ανυψωμένο χείλος να μην μπλοκάρει την άφιξη της μπάλας από
  το τόξο (περνά από κάτω/μέσα του με το ceiling από πάνω).
- Έλεγχος άφιξης (υπολογισμένο): μπάλα στο εσωτερικό του τόξου φτάνει με
  κέντρο (0.554, 0.155) → μόλις κάτω από την οροφή (0.190) ✓ και ήδη σε
  επαφή με το ανυψωμένο χείλος (dist 33.2 ≈ 33) → pivot πάνω του. Πίσω από
  το χείλος, η εξωτερική επιφάνεια του guide (R+2mm) σχηματίζει φυσική
  τσουλήθρα ως το floor (0.128) ✓.
- **Αποτελέσματα (collect_test10)**: 0 collected — παρκάρισμα στο ΙΔΙΟ
  σημείο (fwd -64, z 161, 13s). Το ανυψωμένο χείλος (0.5275) μένει ΕΚΤΟΣ
  του κύκλου εμβέλειας πτερυγίων (83mm = tips 50 + μπάλα 33): το κέντρο
  της μπάλας δεν μπορεί να οδηγηθεί πίσω από το x≈0.548 σε κανένα ύψος —
  sqrt(dx²+dz²)≤83 είναι σκληρό όριο, τα 87.5mm του χείλους δεν
  γεφυρώνονται. Ο ΟΜΟΚΕΝΤΡΟΣ οδηγός δεν μπορεί να έχει έξοδο μέσα στη
  ζώνη οδήγησης.

### 17. Σπειροειδής οδηγός (spiral guide) — test11
- **Αρχή (όπως οι πραγματικοί συλλέκτες)**: η ακτίνα του οδηγού μικραίνει
  προοδευτικά R(φ)=109−14·(φ/φmax), φmax=50° → έξοδος R=95. Χείλος εξόδου
  στο (0.554, 0.183): το κέντρο της μπάλας εκεί απέχει 62mm από τον άξονα
  — ΒΑΘΙΑ μέσα στην εμβέλεια 83mm → τα πτερύγια τη σπρώχνουν ΘΕΤΙΚΑ πάνω
  από το χείλος (προοδευτική σύσφιξη 16-21mm την οποία απορροφούν τα
  πτερύγια λυγίζοντας ~57° < όριο 69°).
- Πίσω από το χείλος: η εξωτερική πλάτη του σπιράλ (R(φ)+2mm) κατεβαίνει
  down-back ως το z=0.128/x≈0.505 → φυσική τσουλήθρα στο extended floor.
- Ceiling ανεβαίνει +40mm (funnel 0.167→0.207) — γίνεται δίχτυ ασφαλείας,
  εκτός τροχιάς εξόδου.
- **Αποτελέσματα (collect_test11, taper 14mm)**: 0 collected — ΝΕΑ
  συμπεριφορά: η μπάλα ΑΝΑΚΥΚΛΩΝΕΤΑΙ (3 κύκλοι grab→άνοδος έως z≈130→
  απόρριψη→πτώση→re-grab) και τελικά διαφεύγει μπροστά. Η στένωση 14mm
  ήταν υπερβολική: απαιτούσε λύγισμα πτερυγίων ~57° και η μπάλα γλιστρούσε
  ανάμεσα στα πλήρως λυγισμένα πτερύγια πριν την έξοδο.
- **Refinement (test12)**: taper 14→**8mm** (λύγισμα ~37°, έξοδος R=101,
  χείλος (0.550, 0.187), κέντρο μπάλας εκεί 68mm < 83mm — ακόμα μέσα στη
  ζώνη θετικής οδήγησης).
- **Αποτελέσματα (collect_test12, taper 8mm + court fix live)**: 0 collected
  αλλά η ΜΕΤΑΦΟΡΑ ΕΙΝΑΙ ΠΛΕΟΝ ΤΕΛΕΙΑ: 33→135mm σε 1.6s, καμία ανακύκλωση,
  πέρασε την έξοδο του σπιράλ — και η μπάλα ΣΥΝΕΧΙΣΕ με τα πτερύγια ΠΑΝΩ
  από την κορυφή του τροχού (z=177 στο fwd -8, πάνω από τον άξονα!) και
  εκτοξεύτηκε ΜΠΡΟΣΤΑ έξω από το robot (fwd +70→120+, εν πτήσει, z 174).
  Νέο failure mode: over-the-top forward launch. (Σημ.: ball rest z=33
  πλέον — court fix #18 ενεργό, νούμερα χωρίς το +10 offset.)

### 19. Επόμενο: stripper plate (test13 — ΔΕΝ έχει υλοποιηθεί)
- Όπως οι πραγματικοί συλλέκτες: «χτενάκι» που ξεκολλάει τη μπάλα από τα
  πτερύγια στην έξοδο του σπιράλ, μπλοκάροντας τη συνέχιση over-the-top.
- **Προδιαγραφή (υπολογισμένη)**: πλάκα με κάτω-εμπρός ακμή στο
  (0.59, 0.185) — απόσταση από άξονα 79mm < 83mm (τέμνει την τροχιά του
  κέντρου της μπάλας) και > 50mm paddle sweep (δεν χτυπούν τα πτερύγια) —
  κεκλιμένη πάνω-πίσω έως ~(0.49, 0.245). Έλεγχος: στο x=0.545 αφήνει
  ~0.21 ελεύθερο για το pivot της μπάλας πάνω από το χείλος του σπιράλ
  (0.550, 0.187). Η υπάρχουσα ανυψωμένη οροφή (0.245) είναι πολύ ψηλά για
  να παίξει αυτό το ρόλο — είτε επανατοποθετείται είτε προστίθεται νέο
  λεπτό stripper στο funnel.urdf.xacro.
- **Status**: ⏳ σχεδιασμένο, για επόμενη συνεδρία.

### 18. Court visual/collision mismatch (οι μπάλες «αιωρούνται»)
- **Ερώτημα χρήστη**: οπτικό ή δεν ακουμπούν το έδαφος; → **Οπτικό.**
- **Αιτία**: στο tennis_court/model.sdf το ground collision (box 0.02) ήταν
  κεντραρισμένο στο z=0 (φυσική επιφάνεια z=+0.01) ενώ το visual είχε pose
  -0.01 (ορατή επιφάνεια z=0). Μπάλες/robot πατούσαν σε αόρατο πάτωμα
  10mm ψηλότερα → φαινομενική αιώρηση. Εξηγεί ΚΑΙ το "court +10mm" quirk
  (ball rest z=43 αντί 33) ΚΑΙ το αρχικό popping των μπαλών στο spawn.
- **Fix**: pose -0.01 και στο collision → φυσική = ορατή επιφάνεια (z=0).
  Ισχύει από το επόμενο restart. Μετά από αυτό: ball rest z=33, το
  court-offset σχόλιο του analyzer παύει να ισχύει (τα gaps βγαίνουν πλέον
  σωστά χωρίς νοητό +10).
- **Status**: ✅ εφαρμόστηκε (θα φανεί στο restart μετά το test11).

## 2026-07-10

### 20. Concept pivot: dual-wheel side pinch (design phase)
- **Context**: το deterministic bench εξάντλησε το single top-roller concept
  (stop/continue gate: "No, reconsider concept" — βλ.
  `intake-concept-decision-el.md`, `intake-bench-sweep-report-el.md`).
- **Αποφάσεις χρήστη (Q&A αυτής της session, ΠΡΙΝ από κάθε αλλαγή
  γεωμετρίας)**: (α) οριζόντιο pinch — δύο τροχοί σε κατακόρυφους άξονες
  αριστερά/δεξιά διαδρόμου· (β) funnel=centering, wheels=capture+transport,
  ramp=elevation προς basket· (γ) actuation με ΔΥΟ πανομοιότυπα μοτέρ (ίδιο
  μοντέλο με του top roller), ένα ανά τροχό, αντίθετης φοράς —
  αντικαθιστά το αρχικό "ένα μοτέρ + γρανάζια" (+1 μοτέρ στο BOM).
- **Spec**: γράφτηκε `docs/dual-wheel-intake-design-el.md` — nominal
  Rw=45mm, gap=60mm (3mm interference/πλευρά), nip x≈0.59, τροχοί
  z 0.005-0.085 (καλύπτουν ισημερινό μπάλας z=33), ω=±45 rad/s.
- **Κρίσιμος υπολογισμός**: ramp end z=0.128 ⇒ v_release ≥1.59 m/s (ιδανικά
  ~2.0 με απώλειες). Το παλιό ζεύγος (30 rad/s × r30) δίνει 0.9 m/s =
  ανεπαρκές· nominal 45 rad/s × Rw45 = 2.03 m/s. Rw και ω = πρώτοι sweep
  axes.
- **Απόδειξη αντικατάστασης**: ίδιο bench, required criteria του decision
  doc με both-wheel contact, 4/5 repeatability, head-to-head vs το
  καλύτερο top-roller case (release 0.133 m/s, no crest).
- **Status**: ✅ spec γραμμένο· εκκρεμεί έγκριση χρήστη πριν την υλοποίηση
  γεωμετρίας (Φάση 1).

### 21. Design review χρήστη: launch → transport φιλοσοφία
- **Αλλαγή πλαισίου (από χρήστη)**: το νέο concept περιγράφεται ως
  `capture → transport → guide → hopper` — ΟΧΙ ως launcher. Συνέπειες:
  - Το required "positive vertical velocity at release" ΚΑΤΑΡΓΗΘΗΚΕ
    (ήταν απαίτηση του launch model)· η ανύψωση είναι ευθύνη του
    guide/ramp σταδίου.
  - Νέα required: both-roller contact, capture through throat, positive
    inward transport, no stall/jam, ramp-entry, hopper-entry ή ramp-crest,
    4/5 repeatability (πλέον required, όχι preferred).
  - Νέα preferred: transport speed >= target, contact duration in range,
    force_p95, lateral offsets, drive-speed variations.
- **Νέες ενότητες στο decision doc**: Initial Dual-Wheel Architecture
  (2 μοτέρ, όχι γρανάζια αρχικά — απλοποίηση drivetrain εξετάζεται ΜΕΤΑ
  την απόδειξη της αρχής), Concept Validation Plan (4 phases: throat only →
  +funnel → +ramp → full intake), Operating Envelope Validation
  (5 representative variations × 4/5 — ρητό αντίδοτο στο narrow-sweet-spot
  failure του top roller).
- **Συνέπεια υλοποίησης**: η γεωμετρία θα μπει με xacro args
  (enable_funnel/enable_ramp) ώστε η Phase 1 να τρέχει ΜΟΝΟ το throat.
  Το transport-speed target (υπολογισμός ~2.0 m/s για ramp z=0.128) γίνεται
  preferred και θα οριστικοποιηθεί με μέτρηση στη Phase 3.
- **Status**: ✅ decision doc + design spec ευθυγραμμισμένα.

### 22. Pre-implementation review: 2 κενά κλείνουν στο spec
- **Λατερική ενδοτικότητα (ΚΡΙΣΙΜΟ)**: το spec έλεγε rigid τροχούς με 3mm
  interference/πλευρά — αλλά rigid+rigid = σφήνωμα (δίδαγμα test1/test2).
  Fix στο spec: κάθε τροχός σε prismatic y-carriage με ελατήριο (SDF patch
  του #9), travel 0..8mm, k~1000 N/m (sweep). Γιατί εδώ δουλεύει ενώ στο
  #13 απέτυχε: η απαιτούμενη υποχώρηση είναι ΣΤΑΘΕΡΑ ±y σε όλη την ευθεία
  διαδρομή (όχι περιστρεφόμενη ακτινική όπως στην τροχιά του roller).
- **Ρεαλιστικό μοτέρ**: πραγματικό hardware = GB37Y3530 12V με encoder
  (collector-wiring-reference). Στο spec μπήκε: effort limit = rated
  torque, ω cap = no-load RPM, jam metric = κατάρρευση joint velocity με
  ενεργό contact (καθρέφτης του encoder jam detection). ⏳ Εκκρεμεί από
  χρήστη το RPM variant του GB37 (το ω=45 rad/s = 430 RPM ίσως υπερβαίνει
  το no-load RPM· τότε Rw → ~0.060).
- Λοιπά: wheels στο base_link (funnel off στη Phase 1)· Phase 1 success =
  διέλευση nip plane με inward velocity· IR beam μετατόπιση στο throat στη
  Phase 4· BOM +1 μοτέρ.
- **Status**: spec πλήρες για υλοποίηση· μόνη ανοιχτή είσοδος το GB37
  variant (δεν μπλοκάρει τη Φάση 0 — μπαίνει placeholder 45 rad/s cap).

### 23. Motor specs επιβεβαιωμένα (GB37Y3530-12V-251R) — recalc ισοζυγίου
- **Specs (χρήστης)**: gear 43.8:1, no-load 251 RPM = 26.3 rad/s, stall
  18 kg·cm = 1.77 N·m, stall 7 A, encoder 16/700 CPR.
- **Συνέπεια**: το placeholder ω=45 rad/s ήταν αδύνατο. Free-run surface
  speed max = 26.3×0.060 = 1.58 m/s ≈ οριακά το v_min (1.59) για momentum
  climb στο z=0.128· υπό φορτίο λαβής droop σε ~1.2 m/s. Μεγαλύτερο Rw
  δεν βοηθά (+torque demand ⇒ +droop, ⌀>120 χτυπά cheeks στο y=±0.145).
- **Απόφαση**: momentum-climb ΔΕΝ είναι ο μηχανισμός ανύψωσης (συνεπές με
  την transport φιλοσοφία #21). Phase 3 μετρά το έλλειμμα· mitigations με
  σειρά: (1) feed-onto-ramp (συνεχής επαφή τροχών πάνω από την αρχή της
  ράμπας), (2) χαμήλωμα hopper entry, (3) Rw 0.070 + μετατόπιση cheeks.
- **Νέα nominal**: Rw=0.060 (⌀120), κέντρα y=±0.090, ω setpoint 25 rad/s,
  effort limit 1.77 N·m, velocity limit 26.3 rad/s,
  COLLECTOR_INTAKE_WHEEL_SPEED default 25. Cheek clearance: wheel outer
  edge y=±0.150 vs cheeks ±0.145 = ΟΡΙΑΚΟ → έλεγχος/προσαρμογή στη Φάση 0.
- **Status**: ✅ spec ενημερωμένο· όλα τα inputs πλήρη — ξεκινά η Φάση 0.

### 24. Υλοποίηση Φάσης 0: dual-wheel γεωμετρία + actuation (offline verified)
- **Γεωμετρία (drivetrain/tennis_robot xacro)**: το `intake_roller`
  αντικαταστάθηκε από `intake_side_wheel` ×2 — carriage (prismatic ±y,
  travel 0..8mm, outward) + κατακόρυφος τροχός (r=0.060, h=0.080) +
  contact sensor ανά τροχό. Nominal: nip (0.590, ±0.090), τροχός σε ground
  z 0.030-0.110 — **ανέβηκε από 0.005** γιατί το κάτω άκρο θα έτεμνε τη
  ράμπα στο πίσω τμήμα των τροχών (ramp z≈0.021 στο x=0.53)· η ζώνη
  εξακολουθεί να καλύπτει τον ισημερινό της μπάλας (0.033).
- **Funnel**: cheeks μετατοπίστηκαν (0.60→0.76, y ±0.145→±0.175) — τα παλιά
  έτεμναν τους τροχούς (51mm < 65mm)· νέο rear-tip handoff (0.647, ±0.146),
  απόσταση 77mm > 68mm (r+travel) ✓. Gating `enable_cheeks`/`enable_ramp`
  στο macro (Validation Phases μέσω INTAKE_ENABLE_FUNNEL/_RAMP envs).
- **Ramp**: entry δένεται στο nip (INTAKE_RAMP_ENTRY_X_M default nip+20mm
  = 0.610) αντί των παλιών roller offsets· lip default 0. Mesh script +
  SDF polyline συγχρονισμένα.
- **Actuation**: `intake_wheel_left/right_joint` (axis z, effort 1.77,
  vel 26.3), controller rename `lift_wheel_velocity_controller` →
  `intake_wheel_velocity_controller` (2 joints)· collector_logic στέλνει
  [-v,+v] (left CW / right CCW top-view → εσωτερικές όψεις προς -x)·
  collector default speed 30→25 rad/s, env COLLECTOR_INTAKE_WHEEL_SPEED
  (fallback στο παλιό όνομα). Launches/bridges/start_sim ενημερώθηκαν·
  bridge roller_contact_0 (left) + **νέο** roller_contact_1 (right).
- **SDF patch (generator)**: fail-loud rebind ΚΑΙ των δύο sensors στα
  lumped collision names ✓, spring patch ΚΑΙ στα δύο carriage joints
  (k=1000 env INTAKE_WHEEL_SPRING_K, ref=0) ✓, μ=2.5 + soft contact στους
  τροχούς ✓.
- **IR throat beam**: x 0.620→0.670 — μέσα στο wheel span (0.53-0.65) θα
  διάβαζε μόνιμα broken. Debug camera: μπροστά-κέντρο (0.78, 0, ground
  0.105) κοιτά πίσω στο throat (η παλιά πλαϊνή θέση πέφτει στον όγκο του
  αριστερού τροχού).
- **Offline verification (γεννημένο SDF, αριθμητικά)**: θέσεις τροχών
  ακριβώς nominal· carriage prismatic axis +y/−y, 0..8mm, k=1000·
  wheel joints effort 1.77 / vel 26.3· sensors→σωστά collisions· καμία
  αναφορά lift_wheel· clearances: ramp-τροχός 7.5mm, cheek-τροχός 9mm,
  basket-τροχός 30mm. **Phase-1 gates δουλεύουν**: generation με
  ENABLE_FUNNEL/RAMP=false δίνει SDF χωρίς cheeks/channel/deflector, με
  τροχούς+sensors παρόντες. Tests: 16/16 περνούν (console/db tests
  σπασμένα προϋπάρχοντα σε αυτό το branch — λείπει το module/deps).
- **Παράπλευρο fix**: start_sim.sh είχε σπασμένο shebang (`k#!`).
- **Εκκρεμεί (live sim)**: επιβεβαίωση counter-rotation σε /joint_states,
  οπτικός έλεγχος, και μετά bench adaptation (probe/analyzer/sweep axes
  είναι ακόμα roller-centric).
- **Status**: ✅ Φάση 0 offline πλήρης → επόμενο: bench adaptation (Task 4)
  και Phase 1 throat-only run.

### 25. Bench adaptation για dual-wheel (transport criteria)
- **sim_physics_probe.py**: dual-wheel geometry (nip/gap/radius/squeeze/bite
  dx από INTAKE_WHEEL_* envs), contact subs ΚΑΙ στα δύο /gz/roller_contact_0
  (left) + _1 (right) — generic `roller_contact_sample` type με νέο πεδίο
  `wheel: left|right` (συμβατό με summarizer), per-wheel sample counters +
  per-wheel joint velocities στο log/summary. Ball tracking πλέον προς το
  nip plane (dx_to_nip, lateral_y).
- **analyze_intake_release_criteria.py (ξαναγράφτηκε)**: transport criteria
  του decision doc με `--phase throat|funnel|ramp|full` gating:
  - Required (πάντα): both-roller contact, capture through throat (κέντρο
    μπάλας περνά το exit plane nip−bite_dx μετά την πρώτη επαφή), positive
    inward transport (ταχύτητα στο capture crossing), no stall/jam (μέγιστο
    συνεχές dwell <0.02 m/s μέσα στη ζώνη intake ≤ 2.0s).
  - Required (ramp/full): ramp climb started (z≥0.05) + crest crossing.
  - Preferred: transport peak ≥ target (0.40 default), contact duration,
    force_p95. Το launch-era "vertical velocity at release" ΔΕΝ υπάρχει
    πια (ρητό note στο output). Repeatability 4/5 = cross-run (sweep level).
- **analyze_intake_bench_poses.py**: nip-centric — απόσταση κέντρου μπάλας
  από τον πλησιέστερο κατακόρυφο άξονα τροχού (xy), radial_gap vs
  Rw+Rball, dx_to_nip.
- **run_native_intake_sweep.sh**: νέοι sweep axes INTAKE_SWEEP_WHEEL_GAPS /
  _WHEEL_RADII / _NIP_XS / _SPRING_KS / _WHEEL_SPEEDS / _DRIVE_SPEEDS /
  _BALL_LATERAL_OFFSETS (envelope), INTAKE_SWEEP_PHASE=throat|funnel|ramp|
  full → θέτει ENABLE_FUNNEL/RAMP. Wheel command `[-v,+v]`. Το
  wait_for_wheel_speed απαιτεί ΚΑΙ τους δύο τροχούς σε ταχύτητα ΚΑΙ
  αντίθετα πρόσημα (left<0<right) — δομικό live check του two-motor wiring
  σε κάθε run (exit 2 σε λάθος φορά).
- **summarize_contact_physics.py**: wheel_left/right_samples + νέα geometry
  πεδία.
- **Offline verification**: synthetic fixtures — pass case δίνει 4/4
  (transport peak 0.50 m/s, stall 0), stall case δίνει 0/4 (stall 5.7s,
  μόνο left contact). Bash syntax OK, όλα τα py compile, κανένα
  lift_wheel/roller-offset υπόλειμμα στο bench path.
- **Εκκρεμότητα (συνειδητή)**: `analyze_collect_bag.py` +
  `run_collect_test.sh` (collect_one flow) μένουν roller-era — αφορούν τη
  Phase 4/full integration, θα προσαρμοστούν τότε.
- **Status**: ✅ bench έτοιμο. Επόμενο: colcon build + Phase 1 throat-only
  live run (INTAKE_SWEEP_PHASE=throat).

### 26. Phase 1 πρώτο live run + διάγνωση contact instrumentation
- **Προεργασία**: σκοτώθηκαν 4 ΟΡΦΑΝΑ headless `gz sim` από παλιά bench
  runs (θα μόλυναν το gz transport — κοινό default partition). Μάθημα:
  πριν από bench run, `pgrep -f "gz sim"`.
- **Run 1 (nominal, gap 60/Rw 60/nip 0.590/k 1000/drive 0.12/ω 25)**:
  - ✅ **Counter-rotation live verified**: wheels_ready left=-25.000
    right=+25.000 — το two-motor wiring σωστό (Task 3 κλείνει).
  - ✅ **Η φυσική της σύλληψης ΔΟΥΛΕΨΕ με την πρώτη**: capture through
    throat = true, inward velocity στο exit plane **0.77 m/s** (6× το
    drive 0.12 — μόνο οι τροχοί μπορούν να την επιτάχυναν· funnel/ramp
    off, τίποτα άλλο μπροστά), κανένα stall. Required 3/4.
  - ❌ 0 contact samples ΚΑΙ στους δύο sensors — αδύνατο φυσικά (gap 60 <
    66) → instrumentation.
- **Διάγνωση (ζωντανό sim + teleport μπάλας στο nip)**:
  - Το gz εκπέμπει τα contact topics στο **world path** (όπου ακούν τα
    bridges) — το explicit `<topic>` του sensor ΔΕΝ είναι το ενεργό.
  - Με μπάλα στατικά στο nip: contact messages ρέουν ΚΑΙ στους δύο
    τροχούς, και το ROS άκρο (`ros2 topic echo /gz/roller_contact_0`)
    λαμβάνει — **bridge chain σωστό end-to-end**.
  - Άρα root cause του 0: η διέλευση είναι **impulsive** — το 3mm/side
    interference + kp 8000 εκτόξευσε τη μπάλα διαμέσου του throat σε
    χρόνο μικρότερο από την περίοδο του sensor (100Hz = 10ms) →
    μηδέν δείγματα παρότι υπήρξε επαφή.
- **Fixes**: sensor update_rate 100→**500Hz** (κοντά στο physics rate) και
  στους δύο τροχούς· `INTAKE_SWEEP_REPEATS` env στο bench (per-case
  επαναλήψεις με suffix _rN) για το required 4/5.
- **Παρατήρηση φυσικής (για τα sweeps)**: η μεταφορά είναι προς το παρόν
  kick, όχι ελεγχόμενο grip — αποδεκτό ως capture+transport, αλλά το
  contact duration/βαθμός ελέγχου είναι ζητούμενο των gap/spring_k sweeps.
- **Επόμενο**: Phase 1 ×5 nominal (τρέχει) → αν both-wheel contact
  επιβεβαιωθεί σε ≥4/5, η Phase 1 περνά.

### 27. Harness fixes + Phase 1 throat-only repeatability PASS
- **Review fixes πριν το τελικό run**:
  - `run_native_intake_sweep.sh`: το bench drive επέστρεψε στο πραγματικό
    live input του `diff_drive_controller`, `/diff_drive_controller/cmd_vel`
    (`TwistStamped`), αλλά πλέον με `header: auto`. Χωρίς live stamp, ο
    controller δεν κινούσε τη βάση. Το intermediate unstamped attempt
    αποδείχθηκε λάθος για το live runtime: το topic info έδειξε subscriber
    στο stamped `/diff_drive_controller/cmd_vel`.
  - Το probe ξεκινάει **πριν** από το drive publisher. Πριν ξεκινούσε μετά
    το `drive_response` και έχανε όλο το impulsive throat event, άρα έβλεπε
    capture από poses αλλά 0 contact samples.
  - `gazebo_extras_node.py`: `/sim/roller_contact` / RViz markers ακούν και
    τα δύο contact topics (`/gz/roller_contact_0`, `/gz/roller_contact_1`).
  - `diagnose_motion.sh`: updated στο νέο
    `/intake_wheel_velocity_controller/commands` με `[-10,+10]`.
  - `docs/dual-wheel-intake-design-el.md`: env typo
    `INTAKE_WHEEL_NIP_X_M` → `INTAKE_NIP_X_M`.
- **Sanity run μετά τα fixes**:
  - Path: `runtime/intake_sweeps/20260710_154459`.
  - Result: required **4/4** σε 1/1. Both-wheel contacts 38/38, contact
    duration 0.096s, capture inward velocity 0.80 m/s, no stall.
- **Phase 1 nominal ×5**:
  - Path: `runtime/intake_sweeps/20260710_154614`.
  - Config: throat-only, gap 60mm, wheel radius 60mm, nip x=0.590,
    spring k=1000 N/m, drive 0.12 m/s, wheel speed 25 rad/s.
  - Result: **PASS 5/5**. Κάθε repeat είχε required **4/4**:
    both-wheel contact, capture through throat, positive inward transport,
    no stall/jam.
  - Contact samples: r1-r4 = 38 left / 38 right, r5 = 35 / 35.
  - Contact duration: 0.080-0.094s. Force max 5.32N, p95 ~4.01-4.08N.
  - Capture inward velocity: 0.76-0.81 m/s, πάνω από το preferred transport
    target 0.40 m/s.
  - Base drive verified live: odom vx ~0.12 m/s και drive wheel velocity
    ~1.41 rad/s σε όλα τα repeats.
- **Συμπέρασμα**: Phase 1 throat-only έχει πλέον αποδειχθεί repeatable για
  centered ball. Το dual-wheel concept περνά το πρώτο gate. Επόμενο λογικό
  βήμα: Phase 2 funnel-only και lateral-offset envelope, όχι ramp/hopper ακόμα.

### 28. Phase 2 funnel-only envelope + boundary repeatability PASS
- **Motor option review**: εξετάστηκε JGB37-3530-1000 12V / 10:1 / 1000 RPM.
  Συμπέρασμα: όχι default για το intake. Με Rw=60mm δίνει ~5.0 m/s rated
  surface speed αλλά μόνο ~0.62N tangential force ανά τροχό στο rated torque
  και ~2.5N στο stall, ενώ το 251RPM μοτέρ έχει πολύ μεγαλύτερο torque
  reserve. Για `capture -> transport -> guide -> hopper` κρατάμε το
  GB37Y3530-12V-251R.
- **Bug στο Phase 2 sweep harness**:
  - Το πρώτο funnel envelope run (`runtime/intake_sweeps/20260710_155624`)
    αποκάλυψε ότι τα lateral offsets ήταν cumulative: κάθε case υπολόγιζε
    `BENCH_BALL_Y` από το ήδη-exported `INTAKE_BENCH_BALL_Y`.
  - Fix: προστέθηκε σταθερό `BENCH_BALL_Y_BASE` και κάθε case κάνει
    `BENCH_BALL_Y = base + lateral_offset`.
- **Καθαρό Phase 2 envelope probe**:
  - Path: `runtime/intake_sweeps/20260710_160008`.
  - Config: funnel-only, ramp off, nominal throat, offsets
    -80/-40/0/+40/+80mm, 1 repeat ανά offset.
  - Result: **PASS 5/5**, required **4/4** σε όλα.
  - Actual `bench_config.txt` επιβεβαίωσε σωστά `ball_y` = -0.08, -0.04,
    0.0, +0.04, +0.08.
  - Κάθε case είχε both-wheel contact 38/38, no stall, capture inward
    velocity 0.54-0.81 m/s.
- **Phase 2 boundary repeatability**:
  - Path: `runtime/intake_sweeps/20260710_160331`.
  - Config: ±80mm offsets, 5 repeats ανά όριο.
  - Result: **-80mm PASS 5/5**, **+80mm PASS 5/5**, required **4/4** σε όλα.
  - +80mm: contact samples 36-38/side, capture velocity 0.74-0.80 m/s,
    no stall.
  - -80mm: 4/5 repeats ισχυρά (38/38 samples, capture velocity 0.72-0.80
    m/s), 1/5 ασθενέστερο αλλά pass (11/10 samples, capture velocity
    0.21 m/s, no stall). Watch item για μελλοντικό wider-offset/approach
    variation, όχι blocker.
- **Συμπέρασμα**: Phase 2 funnel-only περνά για centered και ±80mm lateral
  offsets. Το επόμενο gate είναι Phase 3 ramp-only / feed-onto-ramp, όχι
  αλλαγή μοτέρ.

### 29. Phase 3 ramp-only: collision fixed, handoff still fails; not a motor-first problem
- **Initial ramp run**:
  - Path: `runtime/intake_sweeps/20260710_161533`.
  - Result: required **4/6**. The dual wheels captured and transported the
    ball (`capture_inward_velocity` ~0.69 m/s, both-wheel contact 38/38),
    but the ball stayed at ground height (`z` ~0.033m) and never contacted /
    climbed the ramp.
  - Diagnosis: the SDF `polyline` collision for `intake_channel_col` was
    present but did not behave as a reliable DART collision surface here.
- **Collision fix**:
  - `scripts/generate_robot_urdf.py` now replaces the ramp mesh collision with
    multiple thin, sloped box collision segments instead of one polyline.
  - A temporary axis-aligned box approximation made the ramp "exist" but
    created staircase edges and jams; the current sloped segments follow the
    ramp pitch.
- **Best Phase 3 result so far**:
  - Path: `runtime/intake_sweeps/20260710_162813`.
  - Config: ramp-only, `INTAKE_RAMP_ENTRY_X_M=0.580`, sloped box collision,
    wheel speed 25 rad/s.
  - Result: required **4/6**. The ball now climbs the ramp (`z` crossed
    0.05m at `base_x` ~0.5225), but it does not reach the ramp crest and then
    stalls near the throat / ramp handoff for ~9s.
- **Motor/speed check**:
  - Path: `runtime/intake_sweeps/20260710_162949`.
  - Config: same ramp setup, wheel speeds 35 and 45 rad/s.
  - Results: 35 rad/s stayed **4/6** with ~9.37s stall; 45 rad/s degraded to
    **3/6**. No crest crossing in either case.
  - Conclusion: this is **not** primarily solved by a larger/faster motor.
    The wheels already produce inward transport; the failure is the
    wheel-to-ramp handoff geometry / passive ramp interaction. Next phase-3
    work should examine a smoother/longer handoff, different ramp entry angle,
    or an active second-stage conveyor/roller before changing motor class.

### 30. Phase 3 follow-up: larger wheels and lower ramp target still do not pass
- **Wheel diameter check**:
  - Path: `runtime/intake_sweeps/20260710_164654`.
  - Config: `INTAKE_RAMP_ENTRY_X_M=0.580`, `Rw=70mm`, `nip_x=0.590/0.600`,
    ramp-only, wheel speed 25 rad/s.
  - Results:
    - `Rw=70mm`, `nip_x=0.590`: required **4/6**, climb reached
      `z=0.0543m`, no crest, longest stall ~7.86s.
    - `Rw=70mm`, `nip_x=0.600`: required **4/6**, climb reached
      `z=0.0510m`, no crest, longest stall ~9.32s.
  - Conclusion: larger wheels buy a little better handoff in the best case,
    but do not solve Phase 3. Diameter is not enough by itself.
- **Lower ramp / hopper target check**:
  - Code change: `scripts/generate_curved_scoop_mesh.py` and
    `scripts/generate_robot_urdf.py` now accept
    `INTAKE_RAMP_KNEE_Z_M` and `INTAKE_RAMP_END_Z_M`, so lower handoff
    heights can be tested without hardcoding a new design.
  - Path: `runtime/intake_sweeps/20260710_165010`.
  - Config: `INTAKE_RAMP_ENTRY_X_M=0.580`,
    `INTAKE_RAMP_KNEE_Z_M=0.020`, `INTAKE_RAMP_END_Z_M=0.075`,
    `INTAKE_BENCH_RAMP_CREST_Z_M=0.085`, `Rw=60mm`, ramp-only.
  - Result: required **4/6**. Ball climbed to `z=0.0513m` but still did not
    reach even the lowered crest criterion; longest stall ~8.24s.
  - Conclusion: simply lowering the ramp endpoint is also not enough. The
    failure is the passive handoff after the wheels, before sustained climb.
    Next design branch should add active support after the throat: either
    extend powered contact along the ramp, or add a small conveyor / roller /
    flywheel second stage.

### 31. Phase 3 active assist roller probe: point assist is not enough
- **Code change for fast iteration**:
  - Added optional `enable_assist` second-stage roller with its own
    `assist_wheel_velocity_controller`.
  - Added env-tunable geometry:
    `INTAKE_ASSIST_X_M`, `INTAKE_ASSIST_Z_M`,
    `INTAKE_ASSIST_RADIUS_M`, `INTAKE_ASSIST_LENGTH_M`.
  - The sweep harness records assist geometry in `bench_config.txt` and case
    names, and explicitly spawns/publishes the assist controller in bench
    runs.
- **First hardcoded placement check**:
  - Path: `runtime/intake_sweeps/20260710_170143`.
  - Config: assist true, speed 25 rad/s, old placement
    `x=0.545`, `z=0.050` in `base_link` frame.
  - Result: required **1/6**. The assist roller blocked the capture/ramp
    handoff instead of helping it; capture crossing and ramp climb were both
    false.
  - Diagnosis: too low/too far forward; it becomes an obstacle near the
    throat instead of a second-stage support.
- **Retuned placement sweep**:
  - `runtime/intake_sweeps/20260710_203638`: `x=0.510`, `z=0.075`,
    assist speed +25 rad/s. Result **4/6**: capture true, ramp climb true
    (`z=0.0526m`), no crest, longest stall ~9.21s.
  - `runtime/intake_sweeps/20260710_203812`: `x=0.505`, `z=0.065`,
    assist speed +25 rad/s. Result **4/6**: capture true, ramp climb true
    (`z=0.0508m`), no crest, longest stall ~9.32s.
  - `runtime/intake_sweeps/20260710_203925`: same geometry as above,
    assist speed **-25 rad/s**. Result **4/6**, essentially unchanged
    (`z=0.0508m`, stall ~9.36s). So the main issue is not assist direction.
  - `runtime/intake_sweeps/20260710_204104`: `x=0.505`, `z=0.055`,
    assist speed +25 rad/s. Result **3/6**: ramp climb false, stall ~8.99s.
- **Conclusion**: a single point assist roller has a narrow/no useful window
  in this geometry. Too high barely engages; mid height does not sustain the
  climb; too low becomes another jam/drag point. Phase 3 should pivot from
  "one extra roller" to **active support over length**: short belt/conveyor
  over the ramp, paired roller + compliant lower guide, or a mechanically
  smoother ramp throat that keeps the ball supported after the side wheels.

### 32. Phase 3B conveyor approximation: top rollers alone still do not pass
- **Code change**:
  - Added optional `INTAKE_ENABLE_CONVEYOR=true` prototype: three small
    powered rollers along the ramp (`intake_conveyor_front/mid/rear_joint`)
    controlled by `conveyor_velocity_controller`.
  - Added env knobs:
    `INTAKE_CONVEYOR_SPEED`, `INTAKE_CONVEYOR_X_BIAS_M`,
    `INTAKE_CONVEYOR_Z_BIAS_M`.
  - The model is a Gazebo-friendly approximation of a short belt: not a
    deformable belt, but a quick proof for "active support over length".
- **Offline verification**:
  - `INTAKE_ENABLE_CONVEYOR=true` render creates the 3 conveyor joints in
    URDF/SDF.
  - Flag-off render has no `intake_conveyor_*` links/joints, so Phase 1/2 and
    passive Phase 3 baselines remain comparable.
- **Live runs**:
  - `runtime/intake_sweeps/20260710_204701`: conveyor on, speed +25 rad/s,
    no x/z bias. Result **3/6**: capture true, ramp climb false, stall
    ~7.11s. Front roller was too low/early (bottom around 71mm ground).
  - `runtime/intake_sweeps/20260710_210524`: z-bias +15mm. Result **4/6**:
    capture true, ramp climb true (`z=0.0501m`), no crest, stall ~8.71s.
  - `runtime/intake_sweeps/20260710_210748`: same +15mm but speed **-25**
    rad/s. Result **4/6**, still no crest, stall ~9.12s. Direction is not
    the main blocker.
  - `runtime/intake_sweeps/20260710_210957`: x-bias +30mm and z-bias +15mm
    so the first powered roller starts closer to throat exit. Result **4/6**:
    ramp climb true (`z=0.0527m`), no crest, stall ~9.18s.
- **Conclusion**: top active rollers over the ramp improve/shape the handoff
  but still do not sustain climb. The ball reaches early climb and then falls
  back / stalls around `base_x≈0.566`, which suggests it is not being held in
  the active contact patch. Next mechanical branch should add a **compliant
  lower guide / paired pinch path** over the ramp, or replace the ramp with a
  true belt/conveyor surface that supports the ball from below while driving
  it rearward/upward.

### 33. Phase 3C tilted side wheels: lift appears, but not enough alone
- **User observation**: the side wheels were not tilted upward; they were
  vertical-axis wheels. That meant the dual-wheel stage produced mostly
  rearward transport, not a deliberate upward component toward the ramp.
- **Code change**:
  - Added `INTAKE_WHEEL_TILT_DEG` / `INTAKE_SWEEP_WHEEL_TILTS_DEG`.
  - The side-wheel joint frame is pitched around `y`, so the cylinder axis and
    spin axis tilt together toward `+x`.
  - With the existing command signs (`left=-v`, `right=+v`), positive tilt
    adds upward `z` velocity at the inner contact faces while keeping rearward
    transport.
- **Offline verification**:
  - `INTAKE_WHEEL_TILT_DEG=15` render produced SDF wheel joint poses with
    pitch `0.261799 rad`, confirming the wheels really tilt.
- **Ramp-only sweep**:
  - Path: `runtime/intake_sweeps/20260710_211656`.
  - Config: assist false, conveyor false, `Rw=60mm`, `nip_x=0.590`,
    `INTAKE_RAMP_ENTRY_X_M=0.580`, tilts `0/10/15` deg.
  - `0°`: required **4/6**, ramp climb true (`z=0.0530m`), no crest,
    stall ~9.07s.
  - `10°`: required **3/6**, ramp climb false, no crest, stall ~9.05s.
  - `15°`: required **4/6**, ramp climb true at capture (`z=0.0511m`),
    upward velocity `vz≈0.281m/s`, no crest, stall ~8.67s.
- **Upper bracket**:
  - Path: `runtime/intake_sweeps/20260710_211937`.
  - Config: `tilt=20°`, same ramp-only setup.
  - Result: required **4/6**, ramp climb true (`z=0.0549m`), upward velocity
    `vz≈0.287m/s`, no crest, stall ~8.06s.
- **Conclusion**: tilted side wheels are a better physical mechanism than the
  added top assist/conveyor rollers: they create real upward velocity and
  reduce stall somewhat. But even 20° does not reach the crest. The direction
  is promising, but it still needs either a gentler/lower/longer ramp or a
  short guided support section after the tilted wheels so the ball cannot fall
  out of the active path.

### 34. Tilt 20° + 430RPM motor hypothesis: speed alone still does not pass
- **Question**: maybe the right answer is tilted wheels plus a stronger /
  faster motor?
- **Important harness fix**:
  - The first `tilt=20`, `wheel_speed=45rad/s` run
    (`runtime/intake_sweeps/20260710_212321`) was **not a real 430RPM test**:
    the generated joint/controller velocity limit was still `26.3rad/s`
    (GB37Y3530-12V-251R no-load), and the summary confirmed
    `joint_vel_abs_max_rad_s=26.3`.
  - Added `INTAKE_WHEEL_MAX_VEL_RAD_S` so hypothetical faster motor variants
    can be tested explicitly without changing the default real-motor limit.
- **Actual 430RPM-style run**:
  - Path: `runtime/intake_sweeps/20260710_212523`.
  - Config: `tilt=20°`, `wheel_speed=45rad/s`, `INTAKE_WHEEL_MAX_VEL_RAD_S=45`,
    ramp-only, assist/conveyor off.
  - Verification: summary confirmed `joint_vel_abs_max_rad_s=45.0`.
  - Result: required **4/6**. Ramp climb true (`z=0.0500m`), upward velocity
    `vz≈0.309m/s`, but no crest; longest stall ~8.92s.
- **Conclusion**: 430RPM with 20° tilt increases the upward component, but it
  still does not solve Phase 3. The remaining blocker is not simply motor
  speed; the ball still falls out of the supported/active path before crest.
  A faster motor might be useful later, but the next design change should
  still target ramp/support geometry.

### 35. Tilt 20° + more squeeze at real motor speed
- **Question**: after the 430RPM check, try the real ~251RPM setup with more
  pressure on the ball.
- **Run**:
  - Path: `runtime/intake_sweeps/20260710_212704`.
  - Config: `tilt=20°`, wheel speed `25rad/s`, max velocity `26.3rad/s`,
    assist/conveyor off, gaps `58/56/54mm`, `Rw=60mm`, spring `k=1000`.
- **Results**:
  - `gap=58mm`: required **4/6**, ramp climb true (`z=0.0519m`), no crest,
    stall ~8.82s, capture inward velocity ~1.05m/s.
  - `gap=56mm`: required **4/6**, ramp climb true (`z=0.0618m`), no crest,
    stall ~7.50s, capture inward velocity ~0.91m/s. This is the best
    real-speed squeeze case so far: more lift and shorter stall, but still no
    crest.
  - `gap=54mm`: required **2/6**. Too tight: capture through throat false,
    positive inward transport false, ramp climb false.
- **Conclusion**: more squeeze helps up to a point. `56mm` looks like the
  useful pressure bracket for tilted wheels at real motor speed; `54mm` is too
  much and starts rejecting/jamming before transport. Pressure improves the
  handoff, but still does not replace the need for an easier ramp/support path.

### 36. Drive-motor specs as intake motor: high torque, too slow
- **Question**: try the specs of the existing drive motors as the intake wheel
  motor.
- **Specs used**:
  - DFRobot FIT0403 / drive motor: 12V, **122RPM**, **38kg·cm**.
  - Converted for sim: `INTAKE_WHEEL_MAX_VEL_RAD_S=12.78`,
    `INTAKE_WHEEL_EFFORT_NM=3.73`.
- **Code change**:
  - Added `INTAKE_WHEEL_EFFORT_NM` so motor torque variants can be represented
    explicitly instead of changing only velocity.
- **Run**:
  - Path: `runtime/intake_sweeps/20260710_213247`.
  - Config: `tilt=20°`, `gap=56mm`, `Rw=60mm`, wheel speed/max vel
    `12.78rad/s`, effort `3.73N·m`, ramp-only.
  - Verification: summary confirmed `joint_vel_abs_max_rad_s=12.78`;
    `bench_config.txt` confirmed `wheel_effort=3.73`.
  - Result: required **4/6**. Ramp climb true (`z=0.0530m`), no crest,
    stall ~7.81s, capture inward velocity ~0.68m/s, upward velocity
    `vz≈0.241m/s`.
- **Comparison**:
  - Best GB37 real-speed squeeze case (`25rad/s`, 56mm gap) reached
    `z=0.0618m`, inward ~0.91m/s, `vz≈0.379m/s`, stall ~7.50s.
  - The drive motor's torque is higher, but its 122RPM speed is much lower,
    and in this handoff the extra torque does not compensate for the lost
    surface speed.
- **Conclusion**: existing drive motor specs are not better for the intake
  lift/handoff. They are strong, but too slow for this tilted-wheel transport
  role. Keep the intake closer to the GB37 251RPM class, and solve the
  remaining failure with ramp/support geometry rather than swapping to the
  drive motors.

### 37. Tilt 20° + 251RPM + longer/gentler ramp
- **Question**: αν κρατήσουμε το καλύτερο έως τώρα intake set
  (`251RPM`, `tilt=20°`, `gap=56mm`, `Rw=60mm`) και αυξήσουμε την απόσταση
  της ράμπας ώστε να μικρύνει η κλίση, βοηθάει;
- **Implementation knob**:
  - `scripts/generate_robot_urdf.py` and `scripts/generate_curved_scoop_mesh.py`
    now read `INTAKE_RAMP_KNEE_X_M` and `INTAKE_RAMP_END_X_M`.
  - Defaults remain unchanged (`knee_x=0.520`, `end_x=0.400`), so old runs
    are unaffected unless those env vars are set.
- **Test**:
  - Path: `runtime/intake_sweeps/20260710_213846`.
  - Config: `INTAKE_RAMP_KNEE_X_M=0.470`,
    `INTAKE_RAMP_END_X_M=0.320`, `tilt=20°`, `gap=56mm`,
    wheel speed/max vel `25/26.3rad/s`, assist/conveyor off, ramp-only.
- **Result**: required **4/6**. Capture, both-wheel contact, inward transport,
  and ramp climb are true, but there is still no crest crossing and there is
  still a stall.
- **Useful comparison vs baseline gap=56mm run
  (`runtime/intake_sweeps/20260710_212704`)**:
  - inward transport: `0.91 -> 0.97m/s` (slightly better)
  - ramp climb z at crossing: `0.0618 -> 0.0639m` (about the same / slightly
    better)
  - upward velocity at crossing: `0.379 -> 0.270m/s` (worse)
  - longest stall: `7.50s -> 5.26s` (meaningfully better, but still fails the
    2s criterion)
- **Conclusion**: making the ramp longer/gentler helps, especially by reducing
  the stall, but it is not sufficient alone. It supports the current diagnosis:
  the remaining problem is the unsupported handoff after the tilted wheels. The
  next geometry step should combine the gentler ramp with a short lower/side
  guide or a longer active contact zone, not a motor-only change.

### 38. Short/steep ramp + higher wheel tilt concept
- **Question**: what if we do the opposite of the gentler ramp: shorten the
  ramp so it is closer to ~40°, increase wheel tilt, and accept that the ball
  may be thrown/lobbed instead of softly transported?
- **Test geometry**:
  - Short/steep ramp via `INTAKE_RAMP_KNEE_X_M=0.535`,
    `INTAKE_RAMP_END_X_M=0.450`, with `INTAKE_RAMP_ENTRY_X_M=0.580`.
  - Same motor class: wheel speed/max vel `25/26.3rad/s`, `Rw=60mm`.
- **Runs**:
  - `runtime/intake_sweeps/20260710_214321`: `tilt=40°`, `gap=56mm`.
  - `runtime/intake_sweeps/20260710_214455`: `tilt=40°`, `gap=60mm`.
  - `runtime/intake_sweeps/20260710_214607`: `tilt=25/30/35°`,
    `gap=60mm`.
- **Results**:
  - `40°/56mm`: required **4/6**, inward `1.02m/s`, `vz≈0.425m/s`,
    no crest, contact `8.94s`, stall `8.87s`.
  - `40°/60mm`: required **4/6**, inward `0.77m/s`, `vz≈0.333m/s`,
    no crest, contact `6.74s`, stall `6.64s`.
  - `25°/60mm`: required **4/6**, inward `0.83m/s`, `vz≈0.269m/s`,
    no crest, contact `9.21s`, stall `9.12s`.
  - `30°/60mm`: required **4/6**, inward `0.68m/s`, `vz≈0.260m/s`,
    no crest, contact `9.14s`, stall `9.12s`.
  - `35°/60mm`: required **4/6**, inward `0.73m/s`, `vz≈0.305m/s`,
    no crest, contact `8.70s`, stall `8.63s`.
- **Conclusion**: if throwing/lobbing is acceptable, this concept still needs
  a release mechanism/exit clearance. In sim, the steep-ramp/high-tilt setup
  does not cleanly throw the ball; it keeps it in prolonged wheel contact and
  stalls near the handoff. Opening the gap reduces stall at 40° but also
  reduces inward speed, and lower tilts do not find a better sweet spot. Next
  useful pivot is not more tilt alone, but shaping a short release throat:
  wheels should end before the steep ramp traps the ball, with a small
  backstop/guide or basket lip positioned to catch the lob.

### 39. Wheels closer to base + short handoff bar to basket entry
- **Question**: the wheels should be closer to the base; the old long ramp/bar
  is not the right abstraction. The entry bar should start just before handoff
  and run only to the basket entry.
- **Geometry tested**:
  - `INTAKE_NIP_X_M=0.540`: wheel centre moved closer to the chassis/base
    front edge. With `Rw=60mm`, the wheel rear edge is near `x=0.480`.
  - `INTAKE_RAMP_ENTRY_X_M=0.500`: short bar starts just before the rear
    wheel handoff.
  - `INTAKE_RAMP_END_X_M=0.455`: bar ends near the chassis/basket entry edge.
  - `INTAKE_RAMP_END_Z_M=0.052`: bar surface ends around the chassis top
    height, targeting ball-centre height around `0.085m`.
  - Analyzer target adjusted to `INTAKE_BENCH_RAMP_CREST_Z_M=0.085`.
- **Run**:
  - Path: `runtime/intake_sweeps/20260710_215854`.
  - Config: `tilt=30°`, `gap=60mm`, `Rw=60mm`, wheel speed/max vel
    `25/26.3rad/s`, assist/conveyor off.
- **Result**: required **4/6**.
  - Both-wheel contact true, but now wheel contact is short: `0.34s`
    instead of the multi-second trapped contact seen with the steep long case.
  - Ramp/guide contact is real (`1908` guide samples).
  - Ramp climb starts (`z=0.0548m`) but does not reach the lower basket-entry
    target (`0.085m`).
  - Release velocity points back/down (`vx≈+0.253m/s`, `vz≈-0.343m/s`), so
    the ball is being rejected/falling rather than caught by the bar.
  - Stall still fails (`8.24s`), but the failure mode changed from
    wheel-trap to guide/handoff rejection.
- **Conclusion**: this is a better abstraction than the old long ramp. The
  wheels should indeed sit closer to the base, and the "bar" should be a short
  basket-entry guide, not a long passive climb. However, the first short-bar
  geometry is too abrupt/low or has the wrong catch shape. Next refinement:
  keep this shorter handoff architecture, but shape the guide as a catching lip
  / curved pocket at ~8.5-10cm ball-centre target rather than a simple ramp
  segment.

### 40. Short handoff architecture: pressure, tilt, and wheel diameter sweeps
- **Question**: play with wheel tilt, pressure, and wheel diameter while
  keeping the newer architecture from #39: wheels closer to the base and a
  short handoff bar to basket entry.
- **Base geometry**:
  - `nip_x=0.540`, short bar `x=0.500 -> 0.455`.
  - bar end `z=0.052`, lower basket-entry target `0.085m`.
  - wheel speed/max vel `25/26.3rad/s`, assist/conveyor off.
- **Pressure + tilt sweep**:
  - Path: `runtime/intake_sweeps/20260710_220153`.
  - Grid: gaps `56/58/60mm`, tilts `25/30/35°`, `Rw=60mm`.
  - All cases remained **4/6**: capture + ramp climb true, no basket-entry
    crossing and stall still fails.
  - Notable patterns:
    - tighter gaps (`56/58mm`) produce more lift (`vz≈0.35-0.52m/s`,
      z up to `0.0666m`) but long contact/stall (`~6.5-8.8s`).
    - `gap=60mm` releases quickly at `30/35°` (`~0.34-0.38s` wheel contact)
      but loses lift (`vz≈0.16-0.20m/s`, z around `0.053-0.054m`) and then
      guide rejection/fall remains.
    - `gap=56mm, tilt=35°` had the strongest upward component
      (`vz≈0.523m/s`, z `0.0622m`) but still stalled and did not reach target.
- **Diameter sweep**:
  - Paths: `runtime/intake_sweeps/20260710_220856` and
    `runtime/intake_sweeps/20260710_221125`.
  - Tested `Rw=55/60mm` (diameter `110/120mm`) at `tilt=35°` for
    `gap=58/60mm`. `Rw=65mm` (diameter `130mm`) did not produce a valid
    physics result: the pre-drive wheel readiness check failed twice with
    joint speeds near zero and RTPS SHM port errors in `wheels_ready.log`.
  - `gap=58, Rw=55`: **4/6**, z `0.0516m`, `vz≈0.342m/s`, stall `8.78s`.
  - `gap=58, Rw=60`: **4/6**, z `0.0666m`, `vz≈0.375m/s`, stall `8.65s`.
  - `gap=60, Rw=55`: **4/6**, z `0.0537m`, `vz≈0.187m/s`, contact `0.31s`,
    release velocity down/back (`vz≈-0.237m/s`).
  - `gap=60, Rw=60`: **4/6**, z `0.0552m`, `vz≈0.111m/s`, contact `0.34s`,
    release velocity down/back (`vz≈-0.191m/s`).
- **Conclusion**: diameter is not the missing lever by itself. `120mm`
  diameter is still better than `110mm` for lift in the `58mm` gap case, but
  it does not solve basket-entry. `60mm` gap gives desirable short wheel
  contact, but then the guide must catch/support the ball; otherwise the ball
  is rejected downward. Next mechanical change should be guide shape/catch
  pocket, not more pure parameter sweep.

### 41. ΡΙΖΑ του Phase 3 plateau: το scoop-era basket floor κρεμόταν πάνω από το handoff
- **Ερώτημα**: ποιο είναι το πιο κοντινό σενάριο σε επιτυχία; → Ανάλυση του
  gz_poses του καλύτερου case (#40, gap=56/tilt=35): peak μπάλας
  **z=0.0749 στο dx=0.465** — ΑΚΡΙΒΩΣ το γεωμετρικό όριο κάτω από το
  basket floor: κάτω επιφάνεια slab 0.108 − ακτίνα 0.033 = **0.075**.
- **Διάγνωση**: το basket floor (top 0.128, μπροστινή ακμή x=0.50 — η
  scoop-era «επέκταση» του #15) καλύπτει από ΠΑΝΩ όλη τη ζώνη handoff του
  short bar (0.455-0.50). Η μπάλα χτυπούσε την ΚΑΤΩ πλευρά του πατώματος
  ενώ ανέβαινε (~0.25 m/s) και εκτοξευόταν πίσω-κάτω. Το "guide rejection"
  των #39/#40 ήταν αυτό — όχι κακό σχήμα του bar.
- **Αλλαγή (παραμετροποίηση, defaults ΑΘΙΚΤΑ)**: `basket.urdf.xacro` πήρε
  macro params `floor_front_x` / `floor_top_z_ground` (τοίχοι δένουν πλέον
  στο πάτωμα ώστε να μη ανοίγει πλαϊνό κενό)· xacro args
  `basket_floor_front_x`/`basket_floor_top_z` στο `tennis_robot.urdf.xacro`·
  envs `INTAKE_BASKET_FLOOR_FRONT_X_M` / `INTAKE_BASKET_FLOOR_TOP_Z_M` στον
  generator. Το bench_config.txt γράφει πλέον ΚΑΙ τα ramp/basket geometry
  (έλειπαν — τα #39/#40 δεν είχαν καταγράψει τα ramp env).
  Offline verified: default SDF πανομοιότυπο (front 0.500/top 0.128),
  lowered δίνει front 0.450/top 0.058.
- **Run A (lowered_basket_A)**: floor front 0.45 / top 0.058, bar
  0.500→(0.455, 0.058) flush, best config #40 (nip 0.540, gap 56, tilt 35,
  Rw 60, 25 rad/s), crest target 0.085.
  - Path: `runtime/intake_sweeps/lowered_basket_A`.
  - Αποτέλεσμα: required 3/6 — capture + both-wheel + inward transport ✓,
    ΟΧΙ crest, stall 22s (νέο failure mode: wedge στο (0.494, 0.035) μέσα
    στο πίσω άκρο των τροχών, συνεχής επαφή 21.4s).
  - **Μέτρηση-κλειδί**: ελεύθερο βαλλιστικό apex κέντρου **0.0755**
    (vz 0.51 m/s στο z 0.062)· η μπάλα άγγιξε τη γωνία του πατώματος
    (0.45, 0.058) ακριβώς στο apex (dist=0.033) και αναπήδησε μπροστά.
- **Ενεργειακό ισοζύγιο (από τα δεδομένα)**: ελάχιστο δυνατό hopper floor
  = 0.052 (chassis top) → απαιτεί κέντρο 0.085· το kick δίνει 0.0755 ⇒
  έλλειμμα ~10mm ΣΤΟ apex. Αλλά στο apex η μπάλα κρατά vx=0.93 m/s
  (οριζόντια KE ≈ 44mm ύψους). Η ενέργεια επαρκεί — είναι λάθος
  κατεύθυνσης. Κανένα flat πάτωμα δεν τη σώζει· χρειάζεται καμπύλη
  ανακατεύθυνση (το «catch pocket» του σχεδιασμού).
- **Run B (lowered_basket_B)**: ski-jump μέσω υπάρχοντος ramp profile
  (κανένας νέος κώδικας): entry 0.500, knee (0.455, 0.045), end
  (0.420, 0.085)· floor 0.052/front 0.42· crest 0.080 (πάνω από το
  ελεύθερο apex 0.0755 ⇒ περνά μόνο με πραγματική ανακατεύθυνση)·
  tilts 30/35/40.
  - **tilt 30: required 5/6 — ΠΡΩΤΟ crest crossing σε όλο το Phase 3**
    (peak 0.0823). tilt 35: 5/6, peak **0.0941**. tilt 40: 4/6 (0.0773 —
    πιο απότομο kick, χειρότερη πρόσβαση στο jump).
  - Το redirect δουλεύει: +19mm ύψος πάνω από το βαλλιστικό ταβάνι στο
    tilt 35. Μόνο failure: stall — η μπάλα καρφώνεται στο ΧΕΙΛΟΣ του jump
    (0.42, 0.085): πέρασμα πάνω από lip κοστίζει κέντρο 0.085+0.033=0.118,
    έφτασε 0.094 με ~0 ταχύτητα → γύρισε πίσω στη σφήνα (0.494, 0.035).
  - **Μετρημένο ενεργειακό ταβάνι**: capture E ≈ 0.140-0.146m ισοδύναμο
    ύψος, απώλειες redirect ≈ 0.05m ⇒ κέντρο-ceiling ≈ 0.093-0.094 ⇒
    το lip πρέπει ≤ 0.060 για να περνά το κέντρο (lip+0.033).
- **Run C (lowered_basket_C)**: ίδια αρχιτεκτονική, χαμηλότερο/ηπιότερο
  jump: knee (0.465, 0.020), exit lip (0.425, **0.055**) — μόλις 3mm πάνω
  από το πάτωμα 0.052 (πέρασμα κοστίζει 0.088 < ceiling 0.093, με 5mm
  περιθώριο)· tilts 30/35.
  - **Αποτέλεσμα: required 6/6 ΚΑΙ στα δύο tilts — ΠΡΩΤΟ ΠΛΗΡΕΣ PASS του
    Phase 3 σε όλη την ιστορία του project. Stall 0.00s.**
  - Τροχιά: peak 0.088 πάνω στο χείλος (dx≈0.411) → πέρασμα → προσγείωση
    στο hopper floor → κύλισμα ως το βάθος του καλαθιού, τελική ανάπαυση
    (dx≈-0.06, z=0.085 = κέντρο μπάλας πάνω στο πάτωμα 0.052). Καμία
    επιστροφή πάνω από το 3mm lip, καμία σφήνα στους τροχούς.
  - Inward velocity 1.10 (tilt 30) / 0.76 (tilt 35) m/s.
- **Run C ×5 (lowered_basket_C_x5): PASS 5/5 — το Phase 3 gate ΚΛΕΙΝΕΙ.**
  Κάθε repeat: required 6/6, crest crossing ✓, stall 0.00s, capture inward
  velocity 0.65-0.89 m/s, τελική ανάπαυση εξαιρετικά συνεπής
  (dx=-0.065±0.001, z=0.085 = κέντρο μπάλας πάνω στο hopper floor, βαθιά
  μέσα στο καλάθι). Πρώτο repeatable full-path αποτέλεσμα
  capture→transport→jump→hopper του project (2026-07-10/11).
- **Working γεωμετρία (bench, όλα σε ground frame)**: nip 0.540, gap 56mm,
  Rw 60mm, tilt 35°, GB37 251RPM (25/26.3 rad/s, 1.77 N·m), spring k=1000·
  bar/jump: entry 0.500 → knee (0.465, 0.020) → lip (0.425, 0.055)·
  basket floor top 0.052 (chassis-flush), front edge 0.42· crest
  criterion 0.080.

## 2026-07-11

### 42. Phase 4: full intake (funnel+ramp) + lateral envelope
- Commit checkpoint πριν τη φάση: **79b7020** (όλη η dual-wheel υλοποίηση
  Phase 0-3 + Phase 3 pass, εγγραφές #24-#41).
- **Setup**: winning γεωμετρία του #41 (nip 0.540, gap 56, Rw 60, tilt 35°,
  25 rad/s, jump 0.500→(0.465,0.020)→(0.425,0.055), floor 0.052/0.42,
  crest 0.080), `INTAKE_SWEEP_PHASE=full` (funnel+ramp ΜΑΖΙ πρώτη φορά),
  lateral offsets -80/-40/0/+40/+80mm.
- **Γνωστό ρίσκο προς μέτρηση**: τα funnel cheeks μπήκαν στο #24 για
  nip 0.590 (rear tip x=0.647)· με nip 0.540 υπάρχει ~35mm αφύλαχτο κενό
  cheek-tip→τροχούς. Αν off-centre μπάλες χάνονται εκεί, τα cheeks θα
  μετατοπιστούν πίσω αναλογικά (0.647-0.050).
- **Αποτελέσματα envelope (phase4_full_envelope)**: **PASS 5/5 — required
  6/6 σε ΟΛΑ τα offsets**, stall 0.00s παντού:
  | offset | inward m/s | τελική θέση |
  |---|---|---|
  | -80mm | 0.96 | (-0.065, 0.000, 0.085) |
  | -40mm | 0.72 | (-0.069, 0.000, 0.085) |
  | 0 | 0.80 | (-0.065, 0.000, 0.085) |
  | +40mm | 1.01 | (-0.065, 0.000, 0.085) |
  | +80mm | 1.15 | (-0.068, 0.000, 0.085) |
  Το ρίσκο του cheek-gap ΔΕΝ υλοποιήθηκε: το funnel κεντράρει (τελικό
  y=0.000 σε όλα), κάθε μπάλα καταλήγει στο ίδιο σημείο μέσα στο καλάθι.
  Πρώτο πλήρες funnel+wheels+jump+hopper πέρασμα του project.
- **Boundary repeatability (phase4_boundary_x5): PASS 10/10** — required
  6/6 σε κάθε repeat και στα δύο όρια (±80mm), stall 0.00s παντού,
  inward 0.60-1.11 m/s, τελική θέση (-0.063..-0.068, z 0.085) σε όλα.
  **Το Phase 4 bench gate κλείνει — το dual-wheel concept πέρασε και τις
  4 φάσεις του Concept Validation Plan στο bench.**
- **Εκκρεμότητες για live/full integration (επόμενη δουλειά)**:
  1. **Basket IR beams**: στο `tennis_robot.urdf.xacro` το ζεύγος είναι στο
     `basket_ir_z=0.113` base_link = **0.158 ground** — σχεδιασμένο για το
     scoop-era πάτωμα 0.128. Με το νέο hopper (floor 0.052, μπάλα που
     μπαίνει/κάθεται σε κέντρο 0.085-0.094) η μπάλα ΔΕΝ κόβει ποτέ τη
     δέσμη → το collection count δεν θα μετρήσει. Θέλει χαμήλωμα στο
     ~0.085-0.090 ground (base_link z≈0.040) μαζί με το πάτωμα.
  2. `analyze_collect_bag.py` + `run_collect_test.sh` είναι roller-era
     (συνειδητή εκκρεμότητα #25) — προσαρμογή για το collect_one live test.
  3. Τα νέα ramp/basket bench values να γίνουν defaults του
     sim/run_ubuntu.sh flow όταν επιβεβαιωθεί το live collect_one.

### 43. Live integration: defaults + beams + Jazzy motion chain· approach = νέο μπλόκο
- **Defaults flip (winning γεωμετρία #41-#42 παντού)**: generator + mesh
  script + xacro args + sweep harness + analyzer defaults έγιναν τα
  bench-proven (nip 0.540, gap 56, tilt 35, jump 0.500→(0.465,0.020)→
  (0.425,0.055), basket 0.42/0.052, crest 0.080). Offline verified στο
  env-free SDF. run_ubuntu.sh fallbacks διορθώθηκαν (ήταν 0.590/0.060) και
  το docker-compose πλέον περνά ΟΛΑ τα dual-wheel envs (πριν ΔΕΝ περνούσε
  κανένα — μόνο τα roller-era).
- **Basket IR beams**: 0.158 → **0.085 ground** (ισημερινός μπάλας στο
  hopper). Controller collection zone: BASKET_MIN_BALL_Z 0.12→0.075,
  zone x (0.0,0.42)→(-0.12,0.42).
- **sim.launch.py σέβεται πλέον τα ROBOT_*_FILE env overrides** (ήταν
  hardcoded στα root-owned runtime/ αρχεία — τα stale αρχεία διαγράφηκαν·
  το πρώτο live test διάβασε mode=collect από το παλιό αρχείο).
- **ΡΙΖΑ: η αλυσίδα κίνησης του live ήταν διπλά νεκρή στο native Jazzy**
  (το docker/Humble του run_ubuntu.sh δεν επηρεάζεται):
  1. Ο Ros2MotorAdapter δημοσίευε στο σκέτο `/cmd_vel` → gz bridge → το
     ΑΦΑΙΡΕΜΕΝΟ gz diff-drive plugin. Fix: `/cmd_vel_collection` (twist_mux
     input, priority 70).
  2. Jazzy twist_mux + diff_drive_controller είναι TwistStamped-only
     (κανένα use_stamped param)· όλοι οι producers μιλούν Twist. Fix:
     distro-aware wiring στο sim.launch.py — νέο node
     `cmd_vel_stamp_relay` (Twist→TwistStamped restamp) μπροστά από τα mux
     inputs (collection+teleop) και mux output κατευθείαν στο stamped
     `~/cmd_vel`. Στο Humble μένει η παλιά αλυσίδα αναλλοίωτη.
- **Live collect_one (full stack: Gazebo+YOLO perception+controller)**:
  ο robot πλέον ΚΙΝΕΙΤΑΙ και τρέχει τον πλήρη FSM κύκλο
  (scan→align→approach→capture→reverse_clear) με ζωντανό ball tracking.
  0 collected όμως — **ground truth (48s trace): ελάχιστη απόσταση από
  οποιαδήποτε μπάλα 0.73m**. Τα capture γίνονται στα τυφλά μακριά από
  πραγματικές μπάλες.
- **Νέο μπλόκο (εκτός intake): perception-guided approach.**
  - Η κάμερα (0.443m, 15.6° κάτω) χάνει τη μπάλα στο near field
    (~<0.9m από τη βάση) → το τελευταίο σκέλος είναι dead-reckoning σε
    remembered target με συσσωρευμένο σφάλμα → αστοχία >0.7m.
  - Τα status δείχνουν άλματα distance/target switching (πολλές μπάλες,
    ball_map memory), bearing που δεν συγκλίνει ποτέ <0.07 rad.
  - Το intake ΔΕΝ δοκιμάστηκε live — καμία μπάλα δεν έφτασε στο funnel.
    Το bench-proven capture μένει έγκυρο· το κενό είναι στο να ΦΤΑΣΕΙ
    η μπάλα στο στόμιο.
- **Επόμενα (νέα εκστρατεία, όχι intake)**: (α) near-field στρατηγική —
  χαμηλότερη/δεύτερη κάμερα ή IR-assisted τελική ευθυγράμμιση ή
  approach profile που κλειδώνει heading πριν το blind zone·
  (β) έλεγχος βαθμονόμησης perception bearing/distance→world
  (το πρώτο detection είχε αναντιστοιχία με το ground truth ball_02)·
  (γ) collect_one live rerun με τηλεμετρία gz-vs-perception ανά frame.

### 44. Live approach εκστρατεία: 4 στρώματα διορθώθηκαν, μένει το nip-entry με κυλιόμενη μπάλα
- **Επιβεβαίωση perception**: το πρώτο live detection ταίριαξε με την ball_09
  του κόσμου με σφάλμα **7.5cm στο 1.1m** — το YOLO+depth→world είναι
  βαθμονομημένο σωστά. Το AI pipeline (προσομοίωση OAK-D) λειτουργεί.
- **Στρώμα 1 — παγωμένο lock**: το collect_one κλείδωνε τη θέση-στόχο ΜΙΑ
  φορά στην πρώτη θέαση από το scan (3-5m, μέγιστο σφάλμα) και οδηγούσε
  τυφλά εκεί. Fix: **lock refresh** σε κάθε νεότερη θέαση (gate 0.6m κατά
  του target-stealing) — το σφάλμα πέφτει στο ~7cm της τελευταίας θέασης.
- **Στρώμα 2 — capture profile**: capture από 0.34m με budget 2.8s (0.39m
  τυφλής διαδρομής — δεν έφτανε καν τους τροχούς). Fix: capture_distance
  1.0m (πριν την επαφή με funnel, μέσα στην ορατότητα), timeout 10s,
  commit-ευθεία <0.45m, clamp στο capture steering. Compose capture
  speeds 0.07/0.05 → 0.14 (bench-proven).
- **Στρώμα 3 — τροχοί νεκροί στο capture**: το gate
  `intake_roller_latched |= intake_beam_broken` δεν άνοιγε ΠΟΤΕ live:
  μετρήθηκαν **0/2336 beam fires σε 60s** ενώ ο robot bulldoze-άρει μπάλες
  9.5m! Αιτία: το beam στο x=0.670 (#24 υπολόγισε επαφή στο 0.613) αλλά η
  πραγματική πρώτη επαφή με tilt 35° είναι ball-centre **0.645** → η
  σπρωγμένη μπάλα φτάνει max 0.678 και μόλις γλείφει το beam. Fix διπλό:
  CAPTURE πλέον ΑΓΕΤΑΙ χωρίς gate (committed ingest· το gate μένει στο
  APPROACH για το real-hw σκεπτικό) ΚΑΙ ir_x 0.670→**0.720**.
  Επιβεβαίωση: 2240 samples με τροχούς σε πλήρη περιστροφή στο capture.
- **Στρώμα 4 — odom yaw**: τα nodes κατανάλωναν το ΩΜΟ
  `/diff_drive_controller/odom` (yaw παραμορφωμένο από το wheel_separation
  fudge 1.0 vs 0.70) ενώ το EKF που φτιάχτηκε γι' αυτό τάιζε μόνο TF.
  Fix: `_odom_remap` → `/odometry/filtered`. Παράπλευρο: το EKF απέκλινε
  25m εκτός γηπέδου επειδή fuse-άρει accelerometer ax (double-integration
  runaway) → imu0 πλέον ΜΟΝΟ gyro yaw-rate. Αποτέλεσμα: **lateral aim
  0.00-0.08m** στα capture creeps (μέσα στο ±8cm funnel envelope).
- **Εναπομένον (νέο, καθαρά οριοθετημένο)**: η μπάλα πλέον ΜΠΑΙΝΕΙ στον
  διάδρομο με σωστή στόχευση, αλλά **wedge στη βάση του jump (0.478,
  z=0.037) επί 10s** — το γνωστό wedge pocket του Run A — με kick που
  φτάνει z=0.074 (οριακά κάτω από το χείλος 0.088). Κρίσιμη διαφορά από
  το bench: εκεί η μπάλα ήταν ΣΤΑΤΙΚΗ (σχετική ταχύτητα 0.12 στην επαφή)·
  live η μπάλα ΚΥΛΑΕΙ μπροστά από το robot από την επαφή με το funnel →
  σχεδόν μηδενική σχετική ταχύτητα στο nip → ασθενέστερη αρπαγή.
- **Επόμενη εκστρατεία (bench, deterministic — όχι live whack-a-mole)**:
  αναπαραγωγή του live σεναρίου στο bench (μπάλα που κυλά μπροστά από το
  robot / έλεγχος πραγματικής σχετικής ταχύτητας στην πρώτη επαφή), jam
  instrumentation στο wedge (κατάρρευση joint velocity υπό φορτίο vs
  effort 1.77), και sweep των υποψήφιων μοχλών: wheel speed στο capture,
  commit distance, micro-stop πριν το nip, γεωμετρία εισόδου jump.

## 2026-07-12

### 45. Καλάθι v2: βυθισμένο πλεγματένιο αφαιρούμενο μπιν — PASS envelope + retention
- **Design spec**: `docs/basket-bin-redesign-spec-el.md` (αποφάσεις χρήστη:
  ~50 μπάλες, αφαιρούμενο, πλέγμα· βυθισμένο πάτωμα αντί flap/ψηλού lip).
- **Υλοποίηση**: μπιν x 0.02-0.42 / ±0.14 / πάτωμα **0.030** (25mm
  συγκράτηση κάτω από το lip 0.055, 25mm διάκενο εδάφους) / τοίχοι 0.25·
  ΠΡΑΓΜΑΤΙΚΟ άνοιγμα πλάκας (2 πλαϊνές λωρίδες |y| 0.15-0.29 + πίσω μπλοκ
  x −0.46…0.01)· μπαταρία 6.26kg (19.8×16.6×17) στο πίσω deck
  x −0.226…−0.06 με πραγματική μάζα/αδράνεια (λαμπωμένη βάση 18.9kg)·
  lidar mast (−0.08 → −0.42, εκτός εσωτερικού)· basket IR ζεύγος στο
  **entry plane x=0.40** (στο 0.28 η κυλιόμενη μπάλα με κέντρο 0.063 θα
  περνούσε ΚΑΤΩ από τη δέσμη 0.085)· BASKET_ZONE (0.02, 0.42), half width
  0.14· electronics visual στο aft deck.
- **Παγίδες που πιάστηκαν στην πορεία**:
  1. Πρώτο envelope run απέτυχε 0/5 με τη μπάλα να ΡΟΛΑΡΕΙ (peak 0.061 =
     0.84²/2g·1.4 ακριβώς) αντί να εκτοξεύεται: το harness default για το
     tilt ήταν ακόμα 0.0 — είχα ενημερώσει gaps/nip/crest αλλά ΟΧΙ το tilt
     (fix: 35.0). Δίδαγμα: όταν γυρνάς winning τιμές σε defaults, έλεγξε
     ΚΑΘΕ fallback αλυσίδα (env → harness → generator → xacro).
  2. Το «άνοιγμα σασί = σημείωση κατασκευής» ήταν λάθος: χωρίς πραγματικό
     άνοιγμα στο collision, η μπάλα πατούσε στην ΠΛΑΚΑ (0.052) και το
     retention βάθος δεν υπήρχε στη φυσική. Τα fixed links δεν συγκρούονται
     ΜΕΤΑΞΥ ΤΟΥΣ, αλλά η ΜΠΑΛΑ βλέπει τα πάντα.
  3. Rebuild ΕΝΩ τρέχει sweep = σπασμένο case (controllers inactive).
- **Αποτελέσματα (πλήρες build)**:
  - Envelope (binv2_final_envelope): **PASS 5/5, 6/6 required, stall 0.00**
    σε όλα τα offsets ±80mm. Τελική ανάπαυση (0.073, **z=0.063**) = πάνω
    στο βυθισμένο πάτωμα ✓ (όχι στην πλάκα).
  - **Retention test (πρώτο του project): PASS 15/15** — 15 μπάλες στο
    μπιν, sprint 0.5 m/s + hard stop + spins ±2 rad/s + arcing + απότομη
    όπισθεν: **0 διαφυγές**.
- Εκκρεμή για το concept: rolling-ball nip entry (bench campaign #44) και
  camera blind zone — ανεξάρτητα από το καλάθι. OpenSCAD χτίζεται πάνω στο
  spec.

### 46. Rolling-ball campaign: η κόψη του 0.12 και το χαμηλό lip (v2.1)
- **Deterministic αναπαραγωγή του live #44**: drive-speed sweep
  (rolling_drive_sweep) — στο 0.14/0.25/0.40 η μπάλα φτάνει κυλώντας,
  παίρνει ασθενέστερο kick (peak 0.083/0.076/0.075 αντί 0.088) και
  σφηνώνει ΑΚΡΙΒΩΣ στο live wedge (0.494, 0.036). Αποκάλυψη-κλειδί: και
  το «winning» 0.12 είχε peak 0.088 = ακριβώς την απαίτηση — **το σύστημα
  περνούσε στην κόψη**· +0.02 m/s drive αρκούσε να το ρίξει.
- **Wheel speed 26.3 (max μοτέρ): ΚΑΜΙΑ αλλαγή** στα peaks — η μεταφορά
  ενέργειας είναι γεωμετρικά περιορισμένη, όχι από ταχύτητα (συνεπές
  με #34). Ο μοχλός με headroom είναι η ΑΠΑΙΤΗΣΗ, όχι η προσφορά.
- **Fix (v2.1)**: lip 0.055→**0.045** + πάτωμα μπιν 0.030→**0.025**
  (το βυθισμένο μπιν του #45 έδωσε τον χώρο: συγκράτηση μένει 20mm,
  διάκενο εδάφους 20mm). Απαίτηση εισόδου 0.078 → πραγματικό περιθώριο.
- **Κριτήριο-παγίδα στον analyzer**: με lip 0.045 η μπάλα μπαίνει με pivot
  ~0.077 = ακριβώς το crest plane → το "crossing" δεν καταγραφόταν παρότι
  η μπάλα ΗΤΑΝ στο μπιν (stall 0, rest 0.058). Προστέθηκε τίμιο κριτήριο:
  hopper_entry = τελική θέση ΜΕΣΑ στο μπιν (x 0.02-0.42, z≤0.075) OR
  crest crossing. Το μπιν είναι προσβάσιμο ΜΟΝΟ πάνω από το lip, άρα
  τελική θέση μέσα = απόδειξη εισόδου χωρίς false positive.
- **Αποτελέσματα (νέα defaults: RAMP_END_Z 0.045, FLOOR 0.025,
  crest 0.077)**:
  - Drive sweep 0.12/0.14/0.25: **PASS 3/3**, stall 0.00, in_hopper ✓.
  - Envelope ±80mm @ drive 0.14 (lowlip_final_envelope): **PASS 5/5**.
  - Retention 15 μπάλες + sprint/φρένα/spins/όπισθεν: **PASS 15/15, 0
    διαφυγές** και με τη 20mm συγκράτηση.
- **Συμπέρασμα**: το rolling-ball μπλόκο του live (#44) έκλεισε ΧΩΡΙΣ
  αλλαγή στο control — η γεωμετρία ανέχεται πλέον capture 0.12-0.25 m/s.
  Εκκρεμεί live collect_one rerun για το end-to-end (μαζί με τα camera
  blind zone / approach: η μπάλα πρέπει πρώτα να φτάνει στο funnel).

### 47. Live collect_one end-to-end: PASS controller count, με frame-fix στο /sim/balls
- **Harness fix**: το collect_one driver στο `run_native_intake_sweep.sh`
  είχε παλιό call σε ανύπαρκτο `run_probe_and_summarize`; αντικαταστάθηκε με
  `start_probe` → `wait_for_probe` → `summarize_probe` και ξεκινά πλέον
  `log_gz_poses.py` ώστε το live run να έχει release criteria.
- **Controller/sim fix**:
  - Το Gazebo basket beam μπορεί να ανάψει πριν η μπάλα μπει πραγματικά στο
    hopper, άρα στο sim το collection confirmation πρέπει να έρχεται από
    `/sim/balls` + basket volume και όχι από IR fallback.
  - Το ROS bridge για `/gz/pose_info` δεν είναι αξιόπιστη πηγή entity names.
    Το `gazebo_extras_node` διαβάζει πλέον direct `gz topic /world/.../pose/info`
    και δημοσιεύει `/sim/balls`.
  - Τα Gazebo world coords μετατρέπονται σε odom frame με βάση τη σχέση
    Gazebo robot pose ↔ `/odometry/filtered`; το `gazebo_extras_node` πήρε το
    ίδιο `/odom:=/odometry/filtered` remap με controller/perception.
  - Χαμηλό hopper v2.1: `BASKET_MIN_BALL_Z=0.055` και one-shot guard ανά sim
    ball def για να μη διπλομετράει μέχρι να γίνει remove.
- **Verification**: καθαρό run μετά από rebuild
  `runtime/intake_sweeps/20260712_195801`:
  - `release_criteria`: **required 6/6** (capture, both rollers, ramp climb,
    crest/hopper entry, no stall, positive inward transport).
  - `robot_status/summary`: **balls_collected=1**, `collector_state=survey`,
    mode `collect_one`.
  - `launch.log`: `ball collected -> removing ball_02 from world`.
- **Σημείωση για analyzer**: μετά το successful controller confirmation το sim
  αφαιρεί τη `ball_02` και το probe συνεχίζει να τρέχει όσο το robot επιστρέφει,
  οπότε το `final_in_hopper=false` στο τελικό pose snapshot δεν ακυρώνει το
  end-to-end pass. Για collect_one το authoritative κλείσιμο είναι
  `balls_collected=1` + remove event.

### 48. Physical retention gate: checkpoint PASS, smooth-entry repeatability FAIL

- Προστέθηκε `analyze_basket_evidence.py`: απαιτεί target dwell >=0.75s,
  settled speed <=0.08m/s για >=0.50s, target παρούσα στο τέλος, retention
  όλων των `stored_ball_*` και pitch/roll εντός 8deg. Η άμεση διαγραφή δεν
  μπορεί πλέον να περάσει ως φυσική επιτυχία.
- Το Gazebo κρατά πλέον τη collected μπάλα ως physics entity (legacy remove
  μόνο με `SIM_REMOVE_COLLECTED_BALL=true`). Το `collect_one` έχει stationary
  settle phase με 0.25s intake follow-through πριν από την επιστροφή.
- Το collect-one harness έγινε deterministic: prelaunch `idle`, σειριακοί
  controller spawners, explicit `set_pose` της `ball_02` και απομόνωση των
  υπόλοιπων court balls.
- **Unloaded centre baseline**, `runtime/intake_sweeps/20260712_220758`:
  transport **6/6**, basket evidence **8/8**, dwell 5.268s, settled 0.574s.
- **Controlled y=-0.08**, `runtime/intake_sweeps/20260712_221919`:
  transport **6/6**, target retained, dwell 3.088s, αλλά settled μόνο 0.050s
  → basket evidence **7/8 FAIL**. Η μπάλα κύλησε προς τον πίσω τοίχο και η
  έναρξη επιστροφής την ξανακίνησε πλευρικά.
- **Controlled y=-0.08 με 2s hold**,
  `runtime/intake_sweeps/20260712_222213`: στιγμιαίο collection event αλλά
  τελική target θέση `(x=0.498, y≈0, z=0.034)` έξω μπροστά από το bin,
  transport **5/6**, basket evidence **5/8 FAIL**.
- **Stop gate**: δεν ξεκινά loaded campaign 15/25/45. Το άδειο basket δεν
  έχει ακόμη repeatable smooth settling/retention. Επόμενο πείραμα πρέπει να
  αλλάξει μηχανική απόσβεση/συγκράτηση (rear/side lining, floor friction ή
  entry geometry), όχι να χαλαρώσει τα evidence thresholds.

## 49. Wire-mesh contact model: edge gates 4/5

- Το basket παραμένει κατασκευαστικά **συρμάτινο πλέγμα**, όχι συμπαγές
  κουτί. Τα xacro visuals αποδίδουν ανοιχτό grid 40mm, ενώ τα solid collision
  envelopes παραμένουν μόνο ως ισοδύναμη προσέγγιση για μπάλα 66mm.
- Το generated SDF μοντελοποιεί effective mesh rolling/contact losses:
  `floor mu=1.0`, `wall mu=0.8`, restitution `0.05`, floor `kp/kd=12000/80`
  και wall `kp/kd=4000/120`. Οι τιμές είναι environment-parameterized.
- Single smoke `y=-0.08`, `runtime/intake_sweeps/20260713_082238`: basket
  evidence **8/8**, dwell 7.332s, settled 1.282s, τελική θέση
  `(0.053, -0.107, 0.058)` μέσα στο bin.
- Repeatability `y=-0.08`, `runtime/intake_sweeps/20260713_082401`:
  **4/5 PASS**. Το ένα FAIL κατέληξε έξω μπροστά (`x=0.498`), άρα η
  συγκράτηση βελτιώθηκε αλλά παραμένει οριακή.
- Συμμετρικό edge `y=+0.08`, `runtime/intake_sweeps/20260713_082906`:
  **4/5 PASS**. Το μοναδικό FAIL δεν μπήκε ποτέ στο hopper (`dwell=0`,
  τελική `x=1.075`), επομένως είναι capture/transport failure. Στα τέσσερα
  collected runs η φυσική retention ήταν **4/4**.
- **Gate**: δεν ξεκινά load 15/25/45 πριν περάσουν με 4/5 και οι ενδιάμεσες
  unloaded συνθήκες `y=-0.04,0,+0.04`.

## 50. Passive-carriage instrumentation A/B: το validation μένει OFF

- Το `sim_physics_probe.py` καταγράφει wheel command/actual, robot twist και,
  όταν είναι διαθέσιμα, θέση/ταχύτητα των spring carriages. Για να εκτεθούν
  όμως τα passive carriage joints στο `/joint_states`, πρέπει να δηλωθούν ως
  state-only joints στο `gz_ros2_control`, κάτι που μπορεί να επηρεάσει τον
  τρόπο με τον οποίο το Gazebo χειρίζεται τα joints.
- Προστέθηκε το diagnostic flag `INTAKE_EXPOSE_CARRIAGE_STATE`, με default
  **`false`**. Με `false` τα carriage joints παραμένουν κανονικά στο μηχανικό
  URDF αλλά δεν αποτελούν μέρος του `ros2_control` system. Με `true` εκτίθενται
  μόνο `position`/`velocity`, χωρίς command interface.
- **A/B, unloaded centre, ίδιο collect_one setup, 5 runs ανά condition**:
  - `OFF`, `runtime/intake_sweeps/20260713_111939`: basket evidence **5/5
    PASS**, contact duration `0.336-0.476s`, χωρίς stall και χωρίς carriage
    samples, όπως αναμενόταν.
  - `ON`, `runtime/intake_sweeps/20260713_112506`: basket evidence **4/5
    PASS**. Το FAIL r3 είχε contact duration `17.574s`, wheel median actual
    speed `0rad/s` και τελική target θέση `x=0.497m` μπροστά από το bin. Τα
    carriages έφτασαν περίπου `4.85-4.99mm` στα πέντε runs.
- **Συμπέρασμα**: η καθαρή επιτυχία προηγούμενων instrumentation-ON runs δεν
  αποδεικνύει μηχανική βελτίωση. Το authoritative validation εκτελείται με
  carriage exposure **OFF**. Το ON χρησιμοποιείται μόνο για διάγνωση και τα
  αποτελέσματά του δεν αναμειγνύονται με release-gate datasets.
- **Gate**: το centre case είναι πλέον 5/5 με το authoritative OFF setup, αλλά
  δεν ξεκινά ακόμη load 15/25/45. Πρέπει πρώτα να επαναληφθούν OFF οι
  ενδιάμεσες θέσεις `y=-0.04,+0.04` και να περάσουν τουλάχιστον 4/5.

## 51. Controlled-launch profile: transport PASS, moving retention FAIL

- Προστέθηκε opt-in `INTAKE_RAMP_PROFILE=launch` στον generated SDF. Το
  rolling profile παραμένει default. Το launch kicker χρησιμοποιεί cubic
  Hermite καμπύλη με χαμηλή/οριζόντια είσοδο και παραμετρικά
  `INTAKE_LAUNCH_EXIT_X_M`, `INTAKE_LAUNCH_EXIT_Z_M` και
  `INTAKE_LAUNCH_EXIT_ANGLE_DEG`.
- Πρώτη γεωμετρία: local exit `x=0.465`, `z=0.032`, tangent `35deg`. Με το
  funnel-frame offset, το generated collision τελειώνει περίπου σε
  `x=0.450`, `z=0.030`, με μετρημένη τελευταία κλίση `34.8deg` και air gap
  περίπου 25mm μέχρι το basket lip.
- **Stationary centered bench**, `runtime/intake_sweeps/20260713_121229`:
  **3/3 transport 6/6 και basket evidence 8/8**. Roller contact duration
  `0.099-0.121s`, peak inward speed `1.06-1.08m/s` και μόνο 4 ramp-contact
  samples ανά run. Στο r1 η airborne τροχιά είχε περίπου
  `vx=-0.99m/s`, `vz=+0.52m/s` (`27.5deg`) πριν την είσοδο στο bin.
- **Centered collect_one**, `runtime/intake_sweeps/20260713_121607`:
  controller count **3/3**, αλλά physical basket evidence **0/3 (7/8)**.
  Και οι τρεις μπάλες μπήκαν, έμειναν `4.11-4.21s` και settled για
  `1.57-1.62s`, αλλά μετά την κίνηση του robot κατέληξαν στις μπροστινές
  γωνίες σε `x≈0.444`, έξω από το bin boundary `x<=0.420`.
- **Συμπέρασμα**: ο controlled launch λύνει το rolling-ramp stall και αξίζει
  να συνεχιστεί. Η αρχική αποτυχία δεν ήταν αναπήδηση πάνω από πλήρες lip:
  το 180mm channel άφηνε δύο ακάλυπτες μπροστινές γωνίες 50mm μέσα στο
  basket πλάτους 280mm. Η μπάλα έφτανε κοντά στον πίσω τοίχο, settled, και
  κατά την κίνηση του robot κύλαγε γύρω από το κεντρικό lip.
- Προστέθηκαν δύο mesh-equivalent corner retainers `10x50x20mm` στα
  `x=0.425`, `y=+/-0.115`, αφήνοντας το κεντρικό 180mm launch opening
  ανεπηρέαστο.
- Το πρώτο corrected run στο `runtime/intake_sweeps/20260713_122832` πέρασε
  transport **6/6** και retention **8/8**. Το επόμενο run συλλέχθηκε επίσης,
  αλλά το harness έχασε το probe start window επειδή το launch ολοκληρώθηκε
  πριν από το παλιό threshold 0.45m. Για launch profile το observation window
  ξεκινά πλέον αυτόματα στα 0.70m.
- **Clean corrected retest**, `runtime/intake_sweeps/20260713_123745`:
  **3/3 transport 6/6 και retention 8/8**, stall 0. Τελικές θέσεις
  `x=0.301-0.364`, αντί για `x≈0.444` έξω από τις ανοικτές γωνίες.
- **Official corrected gate**, `runtime/intake_sweeps/20260713_124148`:
  **5/5 transport 6/6 και retention 8/8**, stall 0, με carriage exposure OFF.
  Τελικές θέσεις `x=0.266-0.389`.

## 52. Loaded rollback και ballistic release contract

- Το sweep harness δημιουργεί πλέον πραγματικό preload με ονόματα
  `stored_ball_00...`, ίδιο mass/radius/friction με τις court balls και
  readiness gate που απαιτεί να εμφανιστεί ακριβώς ο ζητούμενος αριθμός στο
  ground-truth pose log πριν ξεκινήσει το `collect_one`.
- Στο πρώτο έγκυρο load-15 run χωρίς κεντρικό χείλος,
  `runtime/intake_sweeps/20260713_132448`, η `stored_ball_09` κύλησε από
  `x=0.35` έξω από το bin στο `x=0.421` ενώ η target ήταν ακόμη στο
  `x=0.859`. Έμεινε στο handoff (`x≈0.428`) και μπλόκαρε την target στα
  `x≈0.491`. Η αστοχία ήταν rollback του φορτίου, όχι αδυναμία motors.
- Προστέθηκε παραμετρικό fixed centre lip `10x180x20mm` στο `x=0.425`, μέσω
  `BASKET_CENTER_LIP_HEIGHT_M` (default `0.020`, `0` για A/B). Το unloaded
  gate `runtime/intake_sweeps/20260713_140430` πέρασε transport **6/6** και
  basket **8/8**. Στα loaded runs συγκράτησε σταθερά **15/15**, άρα λύνει το
  rollback, αλλά η εισερχόμενη μπάλα δεν καθαρίζει την πρώτη σειρά.
- Οι μονοπαραμετρικές αλλαγές δεν έλυσαν το loaded handoff:
  `40deg` (`20260713_141114`) basket **4/8**, `30rad/s`
  (`20260713_144237`) **4/8**, spring `1500N/m`
  (`20260713_144738`) **5/8**. Και στις τρεις περιπτώσεις το φορτίο έμεινε
  15/15, αλλά η target επέστρεψε περίπου στο `x=0.493-0.494`.
- Το νέο `analyze_launch_ballistics.py` κάνει fit με simulation time στα πρώτα
  καθαρά airborne samples. Ξεκινά από το στενό window `x=0.52..0.45` και, όταν
  η ταχύτητα/sampling δώσει λιγότερα από τρία samples, επεκτείνεται αυτόματα
  μόνο μέχρι την πρώτη προσγείωση, αποκλείοντας τη μετέπειτα κύλιση. Γράφει
  release vector, speed, angle, predicted apex/range/front-row
  clearance/landing και target errors στο `launch_ballistics.json` κάθε run.
- **Ballistic contract**: πραγματικό release περίπου `x=0.504,z=0.058`,
  στόχος δεύτερης σειράς `x=0.28`, apex `z=0.135` και first-row clearance
  `z>=0.124`. Η inverse-ballistic λύση από το μετρημένο release point είναι
  περίπου inward `vx=0.893m/s`, `vz=1.231m/s`, speed `1.521m/s`, angle
  `54.1deg`, range περίπου `0.224m`.
- **Τρέχουσα ρύθμιση 35deg/25rad/s/k=1000**, από
  `runtime/intake_sweeps/20260713_140430`: inward `vx=1.019m/s`,
  `vz=0.588m/s`, speed `1.177m/s`, πραγματική γωνία `30.0deg`, predicted
  apex `0.075m`, range `0.122m`, landing `x=0.382`. Υπάρχει ήδη περισσότερη
  από την απαιτούμενη οριζόντια συνιστώσα (`+0.127m/s`), αλλά λείπουν
  `0.644m/s` κατακόρυφης ταχύτητας. Επόμενες αλλαγές αξιολογούνται ως
  calibration map `RPM/angle/gap/stiffness -> actual vx/vz`, όχι μόνο με
  collection count ή ονομαστικές ρυθμίσεις.

## 53. Carriage telemetry και stiffness 1200 N/m

- Με launch geometry `exit x=0.500m`, `z=0.032m`, tangent `70deg`, gap `56mm`
  και `k=1000N/m`, τα carriages άνοιξαν συμμετρικά περίπου `4.93-4.96mm`.
  Δεν τερμάτισαν το διαθέσιμο travel των `8mm`, άρα το nominal squeeze των
  `5mm/side` εφαρμόζεται μέσω των passive springs και δεν είναι rigid jam.
- Το telemetry sweep `20/25/30rad/s` έδειξε ότι τα `20rad/s` αύξησαν την
  επαφή σε `0.685s`, αλλά με χαμηλότερο release speed `1.011m/s`. Τα
  `25rad/s` έδωσαν το καλύτερο `vz/vx=1.065`, ενώ τα `30rad/s` έστρεψαν την
  ενέργεια οριζόντια (`vz/vx=0.778`). Η διάρκεια επαφής μόνη της δεν αρκεί.
- Το πρώτο `k=1200` run στο
  `runtime/intake_sweeps/carriage_telemetry_wspeed_25_k1200_valid` είχε μόνο
  δύο samples στο παλιό στενό ballistic window. Η πραγματική τροχιά ήταν
  διαθέσιμη, αλλά περνούσε περίπου `35mm` ανά sample. Προστέθηκε adaptive
  fit-until-landing και regression test για sparse γρήγορη τροχιά.
- Με τον διορθωμένο analyzer, το πρώτο `k=1200` run έδωσε `5` fit samples,
  speed `1.329m/s`, inward `vx=1.090m/s`, `vz=0.761m/s`, angle `34.9deg`,
  landing `x=0.326` και basket **8/8**. Το repeat
  `carriage_telemetry_wspeed_25_k1200_rerun` έδωσε `6` samples, speed
  `1.234m/s`, `vx=1.073m/s`, `vz=0.610m/s`, angle `29.6deg`, landing
  `x=0.354` και basket **6/8**.
- **Συμπέρασμα**: το `k=1200` αυξάνει κυρίως την οριζόντια μετάδοση και δεν
  είναι repeatable αρκετά για default. Παραμένει experiment· το ballistic
  contract είναι **1/4** και στα δύο runs.

## 2026-07-14
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

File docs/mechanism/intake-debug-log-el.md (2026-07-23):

# Intake roller/lip debugging — log

Σκοπός: αρχείο-καταγραφή για κάθε ενέργεια/διόρθωση γύρω από το intake
(roller, lip, channel, debug camera) ώστε να μην ξαναγυρνάμε στον ίδιο κύκλο.
Νέα εγγραφή ανά αλλαγή: τι δοκιμάστηκε, τι αποτέλεσμα είχε, τι επόμενο βήμα.

## 2026-07-08

### 1. Root cause: channel geometry δεν ακολουθούσε τα intake offsets
- **Βρέθηκε**: `scripts/generate_curved_scoop_mesh.py` και το `_patch_sdf_contacts`
  στο `scripts/generate_robot_urdf.py` είχαν hardcoded `ROLLER_X=0.615`,
  `ROLLER_Z=0.112` — αγνοούσαν τα `INTAKE_ROLLER_X_OFFSET_M` /
  `INTAKE_ROLLER_Z_OFFSET_M` που μετακινούν τον πραγματικό roller μέσω
  `tennis_robot.urdf.xacro`. Επαληθεύτηκε αριθμητικά μέσα από το γεννημένο
  SDF: πριν τη διόρθωση, roller στο `x=0.615,z=0.107` αλλά το channel arc
  center στο `x=0.600,z=0.112` (mismatch 15mm X / 5mm Z).
- **Fix**: και τα δύο scripts διαβάζουν τώρα τα ίδια env vars και μετατοπίζουν
  το channel/mesh μαζί με τον roller.
- **Επαλήθευση**: μετά τη διόρθωση, roller και channel center ταυτίζονται
  ακριβώς (`x=0.615,z=0.107` και τα δύο) στο γεννημένο SDF.
- **Status**: ✅ εφαρμόστηκε, επαληθεύτηκε αριθμητικά.

### 2. Πρώτο `collect_one` test μετά τη διόρθωση
- Στάλθηκε νέα εντολή collect_one (`runtime/robot_command.json`, sequence 60).
- Screenshot από τον χρήστη: μπάλα ακριβώς στο άκρο του intake, στη φάση
  `capture`.
- Λίγο μετά: `collector_state` γύρισε σε `approach`, `collection_count: 0` —
  η προσπάθεια capture ΔΕΝ πέτυχε ακόμα, παρά τη διόρθωση γεωμετρίας.
- **Status**: ⚠️ ανοιχτό — χρειάζεται οπτική/telemetry επιβεβαίωση γιατί
  αποτυγχάνει ακόμα το capture.

### 3. Debug camera (sim-only) — προσπάθεια οπτικής επιβεβαίωσης
- Προστέθηκε `intake_debug_camera.urdf.xacro`: κάμερα mounted στο
  `base_link` (x=0.45, z=-0.03 rel. δηλ. ~15mm πάνω από το έδαφος), pitch
  -0.51 rad (~29° πάνω), gated πίσω από `sim_mode` (μόνο sim). Bridge added
  σε `gazebo/bridge_config.yaml` (`/gz/intake_debug_camera` →
  `/camera/intake_debug/image_raw`).
- **Attempt 1**: πρώτο frame εντελώς μαύρο (min=max=mean=0). Front/oak-d
  camera δούλευε κανονικά (δοκιμάστηκε για σύγκριση) — άρα δεν είναι γενικό
  πρόβλημα rendering pipeline.
- **Υπόθεση A**: η κάμερα κοιτάζει τη σκιασμένη κάτω πλευρά του σασί (ο
  ήλιος της σκηνής δεν φτάνει εκεί) → **Fix**: προστέθηκε spot light
  (`intake_debug_camera_link_spotlight`) στο ίδιο link, ίδια θέση/κατεύθυνση
  με την κάμερα. **Αποτέλεσμα: ΑΚΟΜΑ μαύρο** (frame3.png, min=max=mean=0).
- **Υπόθεση B**: το `<direction>` του spot light στο gz-sim ΔΕΝ περιστρέφεται
  μαζί με το `<pose>` του (γνωστό quirk) — δηλ. direction="1 0 0" σήμαινε
  οριζόντια δέσμη, όχι προς τα πάνω. **Fix**: explicit world-frame direction
  vector (`0.8736 0 0.4870`, υπολογισμένο ώστε να δείχνει ακριβώς στον
  roller target). **Αποτέλεσμα: ΑΚΟΜΑ μαύρο** (frame4.png, min=max=mean=0).
- **Status**: ❌ ανοιχτό μετά από 2 αποτυχημένες υποθέσεις/διορθώσεις.
  Frame παραμένει *ακριβώς* μηδέν (όχι απλά σκοτεινό) σε κάθε προσπάθεια —
  ένδειξη ότι μπορεί να μην είναι θέμα φωτισμού αλλά κάτι πιο δομικό (π.χ.
  τίποτα μέσα στο frustum πριν το far clip, near-clip clipping μέσα σε στερεό
  σώμα, ή κάποιο πρόβλημα στο ίδιο sensor config).
- **Attempt 3 (depth diagnostic)**: προστέθηκε companion depth camera στο ίδιο
  link/γωνία (`/gz/intake_debug_depth` → `/camera/intake_debug/depth`). Το
  depth δεν εξαρτάται από φωτισμό. **Αποτέλεσμα (καθοριστικό)**: και τα 307200
  pixels διάβασαν **0.080–0.087 m** — δηλαδή ένα επίπεδο στερεό ~8cm μπροστά
  γεμίζει ΟΛΟ το κάδρο. Άρα το μαύρο RGB **ΔΕΝ ήταν ποτέ θέμα φωτισμού** — η
  κάμερα ήταν **μπλοκαρισμένη**, κοιτούσε μέσα στη γεωμετρία (πιθανότατα την
  κάτω/πίσω πλευρά του ίδιου του scoop channel) αντί για τον roller στα ~0.19m.
  → Τα δύο light fixes (#3 attempts 1-2) ήταν **λάθος διάγνωση**· δεν χρειάζονταν.
- **Fix (position + light)**:
  - Μετακίνηση κάμερας από head-on underside (`0.45 0 -0.03`) σε **πλάι-κάτω**
    (`base_link 0.5 0.13 -0.02`, ~25mm πάνω από έδαφος, μόλις μέσα από το
    funnel cheek στο y=0.145), με διαγώνια στόχευση inward-up-forward
    (`rpy 0 -0.441 -0.847`) ώστε η γραμμή θέασης να μπαίνει από το πλάι του
    channel όπου δεν υπάρχει εμπόδιο. Απόσταση στον roller 0.192m
    (υπολογισμένη, γραμμή θέασης ελεγμένη ότι δεν τέμνει cheek/chassis).
  - Το spot light έγινε **point light** (omnidirectional) — παρακάμπτει
    τελείως το gz-sim `<direction>` world-frame quirk.
- **Αποτέλεσμα (restart #8)**: ✅ **ΔΟΥΛΕΥΕΙ**. depth τώρα δομημένο
  (0.034–0.218m, 258802/307200 finite, median 0.099) — καθαρή θέαση, όχι
  μπλοκάρισμα. RGB (frame6.png) φωτισμένο (min 0 / max 255 / mean 58). Η
  εικόνα δείχνει καθαρά τον roller (σκούρος κύλινδρος αριστερά-κέντρο) + μια
  κίτρινη μπάλα (πάνω-αριστερά) + φράχτη στο φόντο.
- **Status**: ✅ camera λειτουργεί. **Εκκρεμεί βελτίωση framing**: ο roller
  γεμίζει το κάδρο (η κάμερα είναι ~4cm από το κοντινό άκρο του roller στο
  y=0.09), η μπάλα είναι στη γωνία, το δεξί μισό μαύρο. Για καθαρό "nip
  contact" shot θέλει είτε ευρύτερο FOV (1.0→~1.5) είτε λίγο πιο πίσω/έξω
  τραβηγμένη κάμερα ώστε να κεντραριστεί το σημείο επαφής ball-roller-lip.

### 4. Παράπλευρο fix: RViz markers ποτέ δεν εμφανίζονταν (ξεχωριστό, real bug)
- **Βρέθηκε**: `gazebo_extras_node.py`'s `_on_pose_info` έθετε `self._robot_pose`
  μόνο όταν `child_frame_id.split("::")[-1] == "tennis_robot"` — αλλά το
  `/gz/pose_info` bridge δίνει `child_frame_id=''` για ΚΑΘΕ transform σε αυτή
  την έκδοση του Gazebo (επιβεβαιώθηκε ήδη νωρίτερα ίδια session). Άρα
  `self._robot_pose` έμενε πάντα `None`, και οι publishers
  `/sim/roller_contact_markers` + `/sim/ball_markers` έκαναν σιωπηλά no-op —
  το `RollerContacts` display στο RViz (ήδη υπήρχε στο config) ποτέ δεν
  έδειχνε τίποτα.
- **Fix**: robot pose τώρα έρχεται από `/odom` (nav_msgs/Odometry) αντί για
  το σπασμένο pose_info name-matching.
- **Status**: ✅ εφαρμόστηκε. **Δεν έχει επαληθευτεί ακόμα** ότι τα markers
  όντως εμφανίζονται τώρα στο RViz (δεν έγινε ακόμα δοκιμή με πραγματική
  επαφή μετά τη διόρθωση).

### 5. RViz config
- Προστέθηκε `Image` display για `/camera/intake_debug/image_raw` στο
  `docker/ros2/tennis_robot.rviz` (`IntakeDebugCamera`). Επιβεβαιώθηκε ότι
  εμφανίζεται στο panel (screenshot χρήστη) — αλλά δείχνει μαύρο γιατί η ίδια
  η κάμερα ακόμα δεν βγάζει εικόνα (βλ. #3).

### 6. Framing refinement της debug camera
- **Πρόβλημα**: στο frame6.png ο roller γεμίζει το κάδρο (κάμερα ~4cm από το
  κοντινό του άκρο), η μπάλα πέφτει στη γωνία, το δεξί μισό μαύρο — δεν
  φαίνεται καθαρά το σημείο επαφής ball/roller/lip.
- **Αλλαγή** (θέση ΔΕΝ αλλάζει — είναι επιβεβαιωμένα καθαρή):
  - FOV 1.0 → 1.5 rad (~86°) και στα δύο sensors (RGB + depth).
  - Στόχευση από roller centre (0.615,0,0.107) → **nip midpoint**
    (0.607,0,0.075): `rpy 0 -0.441 -0.847` → `0 -0.289 -0.882`
    (dist 0.176m).
- **Αποτέλεσμα (restart #9)**: ✅ frame7.png δείχνει πλήρες πλάνο: roller
  (πάνω-αριστερά), scoop channel σε σιλουέτα με το lip να ακουμπά το έδαφος,
  court + γραμμή στο φόντο, front-left τροχός. Depth 0.028–1.702m
  (δομημένο, με ορίζοντα). Το nip visible. Η κάμερα-εργαλείο είναι έτοιμη.
- **Status**: ✅ ολοκληρώθηκε.

### 7. Rosbag capture-failure test (instrumented collect_one)
- **Στόχος**: ποσοτική απάντηση στο "αγγίζει η μπάλα τον roller;" — timeline
  απόστασης μπάλας-roller + contact events + joint vel + beam + camera frames.
- **Σημείωση**: το `ros2 bag play` δεν ξανατρέχει φυσική· το test είναι
  record → offline ανάλυση.
- **Εύρημα κατά το setup**: το raw gz `/world/tennis_court/pose/info` ΕΧΕΙ
  entity names — το ros_gz bridge (Pose_V→TFMessage) είναι που τα πετάει
  (child_frame_id=''). Ground truth λοιπόν μέσω `gz topic --json-output` CLI.
- **Εύρημα #2**: μετά το restart #9 ο controller μπήκε ΜΟΝΟΣ του σε
  collect_one (το robot_command.json είχε μείνει σε collect_one) και η
  ball_02 βρέθηκε σπρωγμένη από (-6.4,0) στο (-0.06,0.00) χωρίς capture —
  live αναπαραγωγή του συμπτώματος. → Πριν από restart τεστ, γράφε idle.
- **Εργαλεία** (scripts/sim_debug/): `log_gz_poses.py` (ground-truth
  JSONL ~20Hz), `analyze_collect_bag.py` (bag+JSONL → closest approach,
  contact count, camera frames γύρω από το κρίσιμο σημείο).
- **Bag topics**: /gz/roller_contact_0, /joint_states,
  /collector/intake_beam_broken, /odom, /cmd_vel, /sim/roller_contact,
  /camera/intake_debug/image_raw.
- **Αποτελέσματα (run: collect_test1, bags στο runtime/bags/)**:
  - Ροή: idle → approach (19s) → capture (6s) → reverse_clear, **0 collected**.
  - **Η μπάλα ΑΓΓΙΖΕΙ τον roller**: 496 ball-contact messages στο
    `/gz/roller_contact_0` επί **2.24s συνεχόμενα**. Η υπόθεση "δεν κάνει
    επαφή" **καταρρίπτεται** από τα δεδομένα.
  - Closest approach: κέντρο-κέντρο 69mm → surface gap **-9mm**
    (διείσδυση — συμπίεση από τον solver). Ball κεντραρισμένη τέλεια
    (lateral **0mm**), κέντρο +25mm μπροστά από τον άξονα roller, στο έδαφος
    (z=43mm = rest height).
  - Beam broken 73 δείγματα (η μπάλα στο nip), roller |vel| max 30 rad/s
    (γύριζε κανονικά).
  - Frames: η μπάλα κάθεται στο lip, πιεσμένη στο μπροστινό-κάτω τεταρτημόριο
    του roller, και μένει εκεί — **σφηνωμένη στο λαιμό**, μέχρι που ο robot
    κάνει reverse_clear.
- **Νέα διάγνωση (root cause candidate): ο λαιμός είναι στενότερος από τη
  μπάλα για rigid bodies.**
  - Κάτω διάκενο roller-έδαφος: 107-45 = **62mm** < 66mm μπάλα (το probe το
    τύπωνε ήδη: "ball fit margin=-4.0mm").
  - Το tuning `INTAKE_ROLLER_Z_OFFSET_M=-0.005` ("χαμήλωσε τον roller") το
    προκάλεσε: στο baseline z=112 το διάκενο ήταν 67mm (+1mm ελεύθερο).
  - Κανάλι-roller: 108-45 = 63mm σχεδιαστικά ("3mm nominal interference,
    μοντελοποιεί συμπίεση αφρού") — αλλά o DART με rigid μπάλα ΔΕΝ συμπιέζει:
    η μπάλα απλά δεν χωράει, σφηνώνει (γι' αυτό το 9mm penetration spike), ο
    solver τη σπρώχνει έξω.
  - Το lip raise +2mm στενεύει την είσοδο επιπλέον.
- **Status**: ✅ διάγνωση ολοκληρώθηκε. Επόμενο: A/B rerun με ανοιχτό λαιμό.

### 8. A/B test: άνοιγμα λαιμού (undo roller lowering)
- **Αλλαγή** (ΜΙΑ μεταβλητή): `INTAKE_ROLLER_Z_OFFSET_M=-0.005` → `0.0`
  (roller πίσω στο baseline z=112 → κάτω διάκενο 67mm, +1mm ελεύθερο για
  66mm μπάλα). Κρατάμε `INTAKE_ROLLER_X_OFFSET_M=0.015` και
  `INTAKE_LIP_RAISE_M=0.002` ως έχουν. Το κανάλι ακολουθεί αυτόματα τον
  roller (fix #1), άρα το arc μένει ομόκεντρο.
- **Διαδικασία**: ίδιο instrumented test (collect_test2) για άμεση σύγκριση
  με collect_test1.
- **Κριτήριο επιτυχίας**: μπάλα περνάει το nip (beam → basket beams,
  balls_collected>0), ή τουλάχιστον σαφώς βαθύτερη πρόοδος στο κανάλι αντί
  για static jam 2.2s + reverse_clear.
- **Αποτελέσματα (collect_test2)**: πάλι 0 collected, αλλά με ΑΝΤΙΘΕΤΟ
  μηχανισμό αποτυχίας:
  - test1 (z=-5mm, διάκενο 62mm): μπάλα σταμάτησε +25mm ΜΠΡΟΣΤΑ από τον
    άξονα, 496 contacts επί 2.2s → **σφηνωμένη** στο nip.
  - test2 (z=0, διάκενο 67mm): μπάλα έφτασε +5mm από τον άξονα (σχεδόν από
    κάτω του), beam 57 hits, **0 contacts** — πέρασε ΚΑΤΩ από τον roller με
    ~1mm αέρα **χωρίς να τον αγγίξει ποτέ** → μηδενική πρόσφυση, ο roller
    γύριζε στον αέρα.
  - Σημ.: το court surface είναι ~10mm πάνω από το world z=0 (η μπάλα
    "rest" z=43mm = 33mm ακτίνα + 10mm court) — τα per-frame "surface gap"
    του analyzer έχουν αυτό το offset· τα contact counts του sensor είναι η
    αλήθεια.
- **Συμπέρασμα (διπλό μπλόκο, και τα δύο αποδεδειγμένα)**:
  1. **Grip**: με rigid σώματα, interference = σφήνωμα (test1) και clearance
     = καμία πρόσφυση (test2). Δεν υπάρχει ενδιάμεσο σημείο για σταθερό
     fixed-axis rigid roller — χρειάζεται ΕΝΔΟΤΙΚΟΤΗΤΑ (όπως ο πραγματικός
     αφρός): είτε spring-suspended roller (prismatic joint + spring —
     υποστηρίζεται από DART) είτε soft-contact params (αβέβαιη υποστήριξη
     στο dartsim).
  2. **Πέρασμα**: ακόμα κι αν ο roller έπιανε τη μπάλα, το κανάλι-arc έχει
     διάκενο 108-45=63mm < 66mm μπάλα σε ΟΛΟ το μήκος του ("3mm nominal
     interference" by design) — η μπάλα δεν χωράει πουθενά στη διαδρομή.
     CHANNEL_R πρέπει ≥ 113mm (45+66+2mm slack).
- **Status**: ✅ διάγνωση πλήρης. Επόμενο: fix και των δύο + rerun.

### 9. Fix: spring-suspended roller + κανάλι 113mm (απόφαση χρήστη: μαζί)
- **Αλλαγή A (πέρασμα)**: CHANNEL_R 0.108 → **0.113** και στα δύο σημεία
  (generate_curved_scoop_mesh.py + _patch_sdf_contacts) → διάκενο
  roller-καναλιού 68mm, μπάλα 66mm περνά με 2mm slack.
- **Αλλαγή B (grip)**: ο roller κρεμιέται σε παθητικό prismatic z-joint
  (carriage) με ελατήριο (SDF `<dynamics><spring_stiffness>` — patch στο
  SDF αφού το URDF δεν έχει springs). Rest position με ~8mm interference
  (`INTAKE_ROLLER_Z_OFFSET_M=-0.009` → κέντρο 103mm, κάτω άκρο 58mm για
  μπάλα-top 66mm), ελατήριο k≈300 N/m ώστε η μπάλα να το σηκώνει
  συμπιέζοντας «αφρό» και να δέχεται συνεχή δύναμη πρόσφυσης χωρίς σφήνωμα.
  Travel: 0..+15mm (κάτω stop στο rest, δεν πέφτει από βαρύτητα).
- **Προσοχή**: το contact sensor δείχνει σε συγκεκριμένο lumped collision
  name — με τη νέα δομή (carriage) το όνομα μπορεί να αλλάξει· το patch
  γίνεται δυναμικό (βρίσκει το πραγματικό roller_col collision στο SDF)
  αλλιώς θα μετράμε σιωπηλά 0 contacts.
- **Σφάλμα διαδικασίας (διορθώθηκε)**: το πρώτο collect_test3 δεν έστειλε
  ποτέ collect_one — το runtime/robot_command.json ήταν root-owned (ο
  controller στο container το ξαναγράφει ως root) και το host-side write
  απέτυχε με EACCES. Ο orchestrator στέλνει πλέον την εντολή ΜΕΣΑ από το
  container. Μάθημα: εντολές στο robot_command.json πάντα μέσω
  `docker compose exec`.
- **Αποτελέσματα (collect_test3, spring+113)**: 0 collected ΑΛΛΑ τεράστια
  πρόοδος — **το grip δουλεύει**:
  - t=23.4s: ο roller ΑΡΠΑΞΕ τη μπάλα: fwd +30 → **-64mm** (πίσω από τον
    άξονα), z 43→65mm. Το ελατήριο υποχώρησε (~11mm) όπως σχεδιάστηκε.
  - t=24-35s: η μπάλα ΣΤΑΣΙΜΗ στο fwd≈-43mm, z=46 επί 11s — μέσα στο
    κανάλι, contact μόνο σποραδικό (193 msgs/13s ≈ 15%).
  - t=36s: reverse_clear την άφησε πίσω στο έδαφος.
- **Διάγνωση νεκρής ζώνης**: το z=-9mm κατέβασε το τόξο ώστε πίσω από τον
  άξονα να πέφτει κάτω από το floor clamp (3mm) → επίπεδη τσέπη με κενό
  10+mm από τον roller. Η μπάλα ισορροπεί στο dx=-43 με το κέντρο της
  1.6mm έξω από το grip radius (79.6 vs 78mm) — ο roller γυρνά από πάνω
  της χωρίς επαφή, το τόξο την ξανακυλά πίσω.
- **Refinement (test4)**: z offset -0.009 → **-0.002** (1mm entry bite,
  4mm under-axis squeeze) και CHANNEL_R 0.113 → **0.109** (το τόξο κρατά
  τη μπάλα κολλημένη στον roller πίσω από τον άξονα· max coast gap ~1mm).
  Το ελατήριο μετατρέπει το interference σε grip force αντί για σφήνωμα.
- **Αποτελέσματα (collect_test4, z=-0.002 / R=0.109)**: 0 collected, αλλά
  το τρίτο και βαθύτερο στάδιο μέχρι τώρα:
  - Grip άμεσο και **συνεχής επαφή** (2561 msgs επί 14.4s, vs 193 σποραδικά
    στο test3) — το refinement του τόξου δούλεψε.
  - Η μπάλα **σκαρφάλωσε όλο το τόξο**: fwd +13→-75mm, z 43→**113mm**
    (ύψος άξονα) σε 0.8s.
  - Στάσιμη στο (fwd -75, z 112) επί 13s: σφηνωμένη ανάμεσα σε roller και
    πίσω τοίχο, **γυρνούσε επιτόπου σαν ρουλεμάν** — roller μ=2.5 της δίνει
    spin, τοίχος μ=0.15 δεν το μετατρέπει σε αναρρίχηση (0.15×N ≈
    0.15-0.45N < βάρος 0.57N).

### 10. Fix: τριβή καναλιού 0.15 → 0.8 (test5)
- Το 0.15 ήταν σχεδίαση της rigid εποχής ("μη καρφώνει τη μπάλα") — με το
  sprung roller το pinch είναι πλέον feature.
- **Αποτέλεσμα (collect_test5)**: ΙΔΙΟ stall (fwd -75, z 112, 13s).
  Επαληθεύτηκε ότι το μ=0.8 ΗΤΑΝ live στο SDF — το fix μπήκε, απλά δεν
  έφτανε.

### 11. Διορθωμένο ισοζύγιο + fix: μ=1.4 και spring k=500 (test6)
- **Ποσοτικό ισοζύγιο στο stall point** (fwd -75, z 103, squeeze 2.6mm):
  - Κάτω: βάρος 0.57N + κάθετη συνιστώσα roller-normal 0.08N = 0.65N.
  - Πάνω (τριβή τοίχου, μπάλα-ρουλεμάν): μ_wall × N, με N = k×lift =
    300×2.6mm ≈ 0.78N.
  - μ=0.15 → 0.12N (κολλημένη ✓ ταιριάζει με test4)
  - μ=0.8 → 0.62N vs 0.65N (ΟΡΙΑΚΑ κολλημένη ✓ ταιριάζει με test5!)
  - Το μοντέλο προβλέπει σωστά και τα δύο αποτελέσματα.
- **Fix**: μ_wall 0.8→**1.4** (λάστιχο, όπως οι πραγματικοί συλλέκτες) ΚΑΙ
  spring k 300→**500** N/m → ανοδική ≈ 1.4×1.3 = 1.8N vs 0.65N (2.7×
  περιθώριο). Δύο αλλαγές μαζί σκόπιμα: πολλαπλασιαστικά μέλη του ίδιου
  όρου (μ×N), το ισοζύγιο είναι πλέον μετρημένο.
- **Αποτελέσματα (collect_test6b· το πρώτο test6 χάθηκε από restart-race
  των recorders — μπήκε uptime guard στον orchestrator)**: ΙΔΙΟ stall
  (fwd -75, z 113) και με μ=1.4 + k=500. Δύο διαψεύσεις → το μοντέλο
  «friction-αναρρίχηση» ήταν λάθος επίπεδο ανάλυσης.

### 12. Η πραγματική γεωμετρική αιτία του stall: νεκρή ζώνη #2 (test7)
- **Απόδειξη**: για να περάσει η μπάλα πρέπει το κέντρο της να φτάσει
  ~z=188 (πάνω από το χείλος τοίχου z=155). Η εμβέλεια του roller
  (78mm από άξονα) τελειώνει στο z≈130 στην τροχιά αναρρίχησης → 58mm
  ΧΩΡΙΣ καμία ώθηση. Το design υπέθετε βαλλιστική εκτόξευση, αλλά η
  quasi-static μεταφορά δίνει ~0.67 m/s → άνοδος μόνο 23mm. Καμία τριβή
  δεν γεφυρώνει 58mm κενό — γι' αυτό απέτυχαν το #10 και το #11.
- **Fix (δομικό, όπως οι πραγματικοί συλλέκτες)**: ο κατακόρυφος τοίχος
  αντικαταστάθηκε από **συνέχιση του ομόκεντρου τόξου γύρω από το πίσω
  μέρος του roller** μέχρι z=155 (guide angle έως asin((155-110)/109)≈24°).
  Με ομόκεντρο οδηγό ο roller οδηγεί τη μπάλα ΕΦΑΠΤΟΜΕΝΙΚΑ σε όλη τη
  διαδρομή (η επαφή διατηρείται by construction) και τη ρίχνει από την
  κορυφή με φορά πάνω-πίσω προς deflector/basket.
- Λεπτομέρεια: το underside του collision polygon στο guide τμήμα παίρνει
  ΑΚΤΙΝΙΚΟ offset (R+2mm) — κατακόρυφο offset θα στένευε το πέρασμα 2mm.
- Αρχεία: generate_curved_scoop_mesh.py (νέο profile με GUIDE_STEPS),
  generate_robot_urdf.py (νέο polyline top+underside).
- **Αποτελέσματα (collect_test7)**: ΙΔΙΟ stall (fwd -75, z 113, 26s) και με
  τον ομόκεντρο οδηγό. 4η διαμόρφωση με πανομοιότυπο σημείο καθηλώματος.

### 13. ΤΕΛΙΚΗ ρίζα: 1-DOF κατακόρυφη ανάρτηση ≠ ακτινική ενδοτικότητα
- **Γεωμετρική απόδειξη**: το ελατήριο κινεί τον roller μόνο κατακόρυφα,
  αλλά η μπάλα σε τροχιά γύρω του χρειάζεται ακτινική υποχώρηση ~2mm
  παντού (guide R=109 → πέρασμα 64mm < 66mm μπάλα). Απαιτούμενο vertical
  lift για 2mm ακτινικά: κάτω=2mm ✓· στο fwd -75 = √(78²-75²) =
  **21.4mm > 15mm travel** → μπλόκο ΑΚΡΙΒΩΣ εκεί που κολλάει κάθε test·
  πίσω-οριζόντια=17.7mm· πάνω από τον άξονα: αδύνατον (θα έπρεπε να
  κατέβει κάτω από το rest). Εξηγεί το πανομοιότυπο fwd=-75 των tests
  4/5/6b/7 ανεξαρτήτως τοίχου/τριβής/ελατηρίου/οδηγού.
- Ο αληθινός αφρός συμπιέζεται ΑΚΤΙΝΙΚΑ (υλική ενδοτικότητα), όχι σαν
  ανάρτηση άξονα.
- **Επόμενο fix (μεγάλο αλλά το πρώτο γεωμετρικά ικανό): paddle roller**
  — hub + 6 πτερύγια σε revolute joints με ελατήρια (SDF patch όπως το
  carriage). Κάθε πτερύγιο λυγίζει ακτινικά → πραγματική ενδοτικότητα σε
  όλη την τροχιά. Ιστορικό εύρημα: τα bridges roller_contact_0..7 και το
  σχόλιο "Real physics contacts from each intake paddle" δείχνουν ότι το
  ΑΡΧΙΚΟ design ήταν paddle wheel — η απλοποίηση σε συμπαγή κύλινδρο
  είναι που αχρήστεψε τη φυσική της σύλληψης.
- **Status**: εγκρίθηκε από χρήστη → υλοποίηση στο #14.

### 14. Υλοποίηση paddle roller (test8)
- **Δομή**: `lift_wheel_link` γίνεται hub (κύλινδρος r=25mm, το ros2_control
  joint `lift_wheel_joint` μένει ίδιο, ξανά απευθείας στο base_link) + 8
  πτερύγια (boxes 25×180×4mm) το καθένα σε δικό του revolute joint
  (±1.2 rad) με SDF-patched spring (k=0.25 N·m/rad, damping 0.02,
  reference 0). Tips στα 50mm — ελαφρώς μεγαλύτερο envelope από τον παλιό
  κύλινδρο (45), συμπιέσιμο ακτινικά έως ~hub.
- **Το κατακόρυφο carriage (#9) ΑΦΑΙΡΕΘΗΚΕ** — με ακτινική ενδοτικότητα
  ανά πτερύγιο είναι περιττό, και το travel-limit του ήταν το μπλόκο του #13.
- **Sensors**: ένα contact sensor ανά πτερύγιο → roller_contact_0..7 — τα
  8 bridges που υπήρχαν ήδη ξαναγεμίζουν όλα. Το SDF patch δένει δυναμικά
  κάθε sensor στο collision του αντίστοιχου paddle link (fail-loud αν
  λείπει κάποιο από τα 8).
- **Τριβές**: paddles μ=2.5 (λάστιχο), hub μ=0.8. Κανάλι μένει μ=1.4,
  guide R=109 (πέρασμα 59mm vs tips → τα πτερύγια λυγίζουν ~40° στο nip,
  δύναμη λαβής ~7N).
- **Αποτελέσματα (collect_test8)**: 0 collected αλλά **το paddle roller
  λύνει το radial-compliance πρόβλημα**:
  - Η μπάλα μεταφέρθηκε σε ΟΛΟ το τόξο: fwd +15→-76, z 43→**171mm** σε
    1.6s — πέρασε το μοιραίο fwd -75 (πρώτη φορά σε 8 tests) ΚΑΙ το
    guide release (155).
  - Μετά: **juggle** στην κορυφή του τροχού (fwd -66, z≈167) επί 12s — στην
    κορυφή τα πτερύγια κινούνται ΜΠΡΟΣΤΑ (φυσική του τροχού: πάνω=+x),
    οπότε δεν μπορούν να σπρώξουν τη μπάλα πίσω προς το καλάθι.
  - Σημ. ανάλυσης: το bag γράφει μόνο roller_contact_0 (1 από 8 πτερύγια)
    — στο επόμενο test προσθήκη και των 8 στο record list.
- **Εναπομένον πρόβλημα (το τελευταίο): handoff στο καλάθι.**
  - Ο υπάρχων deflector (ground z 204-266) σχεδιάστηκε για βαλλιστική
    εκτόξευση· η paddle-μεταφορά δίνει peak μόλις ~204 (οριακό άγγιγμα).
  - Γεωμετρικός περιορισμός: το πάνω μέρος του τροχού πάντα οδηγεί ΜΠΡΟΣΤΑ
    — η μπάλα πρέπει να φύγει από τον τροχό και να ταξιδέψει πίσω είτε
    βαλλιστικά είτε από στατική επιφάνεια. Επιπλέον το basket floor top
    (ground 128, front edge x=0.42) απαιτεί κέντρο μπάλας ~161 για να
    πατήσει — το guide exit δίνει 141 (το juggle έδινε 167).
  - Υποψήφιο πακέτο (test9): (α) οροφή-deflector ΠΙΣΩ-ψηλή (front-low) πάνω
    από το juggle ώστε η ανοδική-εμπρός κρούση να ανακλάται πίσω-κάτω,
    (β) επέκταση basket floor μπροστά (x→~0.50) ώστε η μπάλα που πέφτει
    πίσω από το guide sheet να προσγειώνεται σε πάτωμα και όχι στο κενό
    (x 0.42-0.50 σήμερα δεν έχει τίποτα από κάτω), (γ) πιθανό μέτριο speed
    bump για ενέργεια. Θέλει σχεδιασμό με τα juggle kinematics από το bag.
- **Status**: paddle roller ✅ λειτουργεί· handoff → #15.
- Commit checkpoint: 4cc7886 (paddle roller + εργαλεία + log).
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

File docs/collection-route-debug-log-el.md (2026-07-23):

# Collect-route debug log (ενεργό)

> Το προηγούμενο log βρίσκεται στο `docs/archive/`. Εδώ καταγράφεται κάθε
> αλλαγή του collect_route rewrite με υπόθεση / αποτέλεσμα / status.

## #1 — Φάση 2R fixes από review 2026-07-20: σπασμένο runtime session + single source coverage

- **Υπόθεση:** Το `CollectionSnapshotRuntimeSession` έσπασε (TypeError) επειδή ο
  `ScanSnapshotBuilder` απέκτησε required `expected_scan_step_ids` /
  `required_coverage_fraction` / `scan_timeout_s` και `finalize(now_s)` χωρίς να
  ενημερωθεί το session. Παράλληλα, τα `required_coverage_fraction` και
  `scan_timeout_s` ως ctor args ήταν δεύτερη πηγή αλήθειας δίπλα στο
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

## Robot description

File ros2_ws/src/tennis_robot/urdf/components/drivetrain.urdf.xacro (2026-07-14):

<?xml version="1.0" encoding="UTF-8"?>
<robot xmlns:xacro="http://www.ros.org/wiki/xacro">
  <xacro:macro name="drive_motor" params="side y motor_x shaft_z radius length mass">
    <link name="${side}_motor_link">
      <xacro:cylinder_inertial mass="${mass}" radius="${radius}" length="${length}" axis="y"/>
      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
    </link>
    <joint name="${side}_motor_mount_joint" type="fixed">
      <parent link="base_link"/>
      <child link="${side}_motor_link"/>
      <origin xyz="${motor_x} ${y} ${shaft_z}" rpy="0 0 0"/>
    </joint>
  </xacro:macro>

  <xacro:macro name="drive_wheel" params="side y wheel_x wheel_z radius width mass">
    <link name="${side}_wheel_link">
      <xacro:cylinder_inertial mass="${mass}" radius="${radius}" length="${width}" axis="y"/>
      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
    </link>
    <joint name="${side}_wheel_joint" type="continuous">
      <parent link="base_link"/>
      <child link="${side}_wheel_link"/>
      <origin xyz="${wheel_x} ${y} ${wheel_z}" rpy="0 0 0"/>
      <axis xyz="0 1 0"/>
      <dynamics damping="0.001"/>
    </joint>
    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
  </xacro:macro>

  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
  <xacro:macro name="intake_side_wheel" params="side y nip_x wheel_z tilt_rad radius height carriage_travel max_vel effort mass sensor_index">
    <link name="intake_wheel_${side}_carriage_link">
      <inertial>
        <mass value="0.05"/>
        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
      </inertial>
      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
    </link>
    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
    <joint name="intake_wheel_${side}_carriage_joint" type="prismatic">
      <parent link="base_link"/>
      <child link="intake_wheel_${side}_carriage_link"/>
      <origin xyz="${nip_x} ${y} ${wheel_z}" rpy="0 0 0"/>
      <axis xyz="0 ${1 if y >= 0 else -1} 0"/>
      <limit lower="0" upper="${carriage_travel}" effort="200" velocity="1.0"/>
      <dynamics damping="8.0"/>
    </joint>
    <link name="intake_wheel_${side}_link">
      <xacro:cylinder_inertial mass="${mass}" radius="${radius}" length="${height}" axis="z"/>
      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
    </link>
    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
    <joint name="intake_wheel_${side}_joint" type="continuous">
      <parent link="intake_wheel_${side}_carriage_link"/>
      <child link="intake_wheel_${side}_link"/>
      <origin xyz="0 0 0" rpy="0 ${tilt_rad} 0"/>
      <axis xyz="0 0 1"/>
      <limit effort="${effort}" velocity="${max_vel}"/>
      <dynamics damping="0.005"/>
    </joint>
    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
  </xacro:macro>

  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
  <xacro:macro name="intake_ramp_conveyor_roller" params="name parent x z radius length mass">
    <link name="${name}_link">
      <xacro:cylinder_inertial mass="${mass}" radius="${radius}" length="${length}" axis="y"/>
      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
    </link>
    <joint name="${name}_joint" type="continuous">
      <parent link="${parent}"/>
      <child link="${name}_link"/>
      <origin xyz="${x} 0 ${z}" rpy="0 0 0"/>
      <axis xyz="0 1 0"/>
      <limit effort="1.77" velocity="26.3"/>
      <dynamics damping="0.005"/>
    </joint>
    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
  </xacro:macro>

  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
  <xacro:macro name="intake_assist_roller" params="parent x z radius length mass">
    <link name="intake_assist_wheel_link">
      <xacro:cylinder_inertial mass="${mass}" radius="${radius}" length="${length}" axis="y"/>
      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
    </link>
    <joint name="intake_assist_wheel_joint" type="continuous">
      <parent link="${parent}"/>
      <child link="intake_assist_wheel_link"/>
      <origin xyz="${x} 0 ${z}" rpy="0 0 0"/>
      <axis xyz="0 1 0"/>
      <limit effort="1.77" velocity="26.3"/>
      <dynamics damping="0.005"/>
    </joint>
    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
  </xacro:macro>

  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
</robot>

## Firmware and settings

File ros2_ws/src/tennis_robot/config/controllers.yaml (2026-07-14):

# ros2_control controller configuration for the tennis robot.
#
# Loaded by the gz_ros2_control-system plugin (sim) or a standalone
# controller_manager node (real robot). These names/params are the stable
# contract the behavior stack targets — identical for sim and hardware.
#
# Controllers:
#   joint_state_broadcaster      -> publishes /joint_states (+ feeds /tf via RSP)
#   diff_drive_controller        -> /diff_drive_controller/cmd_vel_unstamped (Twist) -> wheels, publishes odom + tf
#   intake_wheel_velocity_controller -> /intake_wheel_velocity_controller/commands
#     (Float64MultiArray [left, right]) -> dual-wheel intake. Forward intake
#     is [-v, +v]: left wheel clockwise / right counter-clockwise (top view)
#     so both inner faces drive rearward (-x).
#   assist_wheel_velocity_controller -> /assist_wheel_velocity_controller/commands
#     (Float64MultiArray [v]) -> optional ramp assist roller. Forward assist is
#     +v: bottom surface drives rearward (-x).
#   conveyor_velocity_controller -> /conveyor_velocity_controller/commands
#     (Float64MultiArray [front, mid, rear]) -> Phase 3B ramp conveyor
#     approximation with three small powered rollers.

controller_manager:
  ros__parameters:
    update_rate: 100  # Hz

    joint_state_broadcaster:
      type: joint_state_broadcaster/JointStateBroadcaster

    diff_drive_controller:
      type: diff_drive_controller/DiffDriveController

    intake_wheel_velocity_controller:
      type: forward_command_controller/ForwardCommandController

    assist_wheel_velocity_controller:
      type: forward_command_controller/ForwardCommandController

    conveyor_velocity_controller:
      type: forward_command_controller/ForwardCommandController

diff_drive_controller:
  ros__parameters:
    # 4WD skid-steer: two driven wheels per side, both commanded together.
    left_wheel_names: ["rear_left_wheel_joint", "front_left_wheel_joint"]
    right_wheel_names: ["rear_right_wheel_joint", "front_right_wheel_joint"]

    # Geometry — keep in sync with urdf/tennis_robot.urdf.xacro
    # Geometric track = 2 * wheel_y = 0.70 m. BUT this is a 4WD skid-steer: the
    # wheels scrub sideways when turning, so the EFFECTIVE rotational track is
    # larger than the geometric one. Using 0.70 made odom OVER-estimate yaw, which
    # smeared the SLAM map into a pinwheel and failed the court survey.
    # 1.0 ~= 0.70 * 1.4 (typical skid-steer correction). TUNE: if the SLAM map
    # still over-rotates raise this; if it under-rotates lower it toward 0.70.
    wheel_separation: 1.0
    wheel_radius: 0.085  # 170 mm HPI Dirt Buster Block wheels (was 0.09 / 180 mm)

    # Plain geometry_msgs/Twist on ~/cmd_vel_unstamped (use_stamped_vel: false)
    use_stamped_vel: false
    # NOTE: must stay < ~2.1e6 s. The controller computes
    # static_cast<int>(timeout * 1000) ms — larger values overflow int32 to a
    # NEGATIVE timeout, so every command is treated as expired and zeroed
    # (robot accepts Twist but never moves). The old 1.0e9 hit exactly this.
    cmd_vel_timeout: 5.0

    publish_rate: 50.0
    # Diagnostic tap: republishes the command as the controller processed it
    # on ~/cmd_vel_out. Shows whether messages actually reach the controller.
    publish_limited_velocity: true
    odom_frame_id: odom
    # base_footprint (not base_link): the URDF already publishes
    # base_footprint -> base_link via robot_state_publisher. Pointing odom at
    # base_link would give base_link two TF parents and orphan base_footprint.
    # Chain: map -> odom -> base_footprint -> base_link
    base_frame_id: base_footprint
    # EKF (robot_localization) now publishes odom -> base_footprint by fusing
    # this odometry with the IMU. diff_drive still publishes the /odom TOPIC
    # (consumed by the EKF) but must NOT also broadcast the TF, or it fights the
    # EKF for the same transform.
    enable_odom_tf: false
    open_loop: false

    pose_covariance_diagonal: [0.001, 0.001, 0.0, 0.0, 0.0, 0.01]
    twist_covariance_diagonal: [0.001, 0.001, 0.0, 0.0, 0.0, 0.01]

    # Velocity/acceleration limits — DISABLED for now. With only max (no min) set,
    # the limiter could clamp the output to 0 under sim time. Re-enable later with
    # matching min_velocity / min_acceleration values.
    linear.x.has_velocity_limits: false
    linear.x.has_acceleration_limits: false
    angular.z.has_velocity_limits: false
    angular.z.has_acceleration_limits: false

intake_wheel_velocity_controller:
  ros__parameters:
    joints: ["intake_wheel_left_joint", "intake_wheel_right_joint"]
    interface_name: velocity

assist_wheel_velocity_controller:
  ros__parameters:
    joints: ["intake_assist_wheel_joint"]
    interface_name: velocity

conveyor_velocity_controller:
  ros__parameters:
    joints: ["intake_conveyor_front_joint", "intake_conveyor_mid_joint", "intake_conveyor_rear_joint"]
    interface_name: velocity

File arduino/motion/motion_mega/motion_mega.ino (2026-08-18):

/*
 * motion_mega.ino - Tennis robot DRIVE motion MCU (Arduino Mega 2560)
 * ---------------------------------------------------------------------------
 * 4WD skid-steer. Two BTS7960 drivers (one per side), four encoders.
 * The Mega is the real-time / safety layer; the host (PC now, Pi later) sends
 * high-level per-side duty over USB serial. Same protocol works on PC and Pi
 * (USB CDC is host-agnostic).
 *
 * SAFETY MODEL
 *   - Boots DISARMED: drivers disabled (EN low), duty 0.
 *   - ARM only if E-stop status not tripped.
 *   - Command timeout: if no command/heartbeat within CMD_TIMEOUT_MS, duty -> 0
 *     (stays armed, but motors stop). Host must stream heartbeats.
 *   - PWM ramp (slew-rate limit) toward target -> avoids current spikes that
 *     would trip the battery BMS during skid-steer turns.
 *   - E-stop status (active-low, optional aux contact) forces DISARM.
 *   - The local START/ARM button can arm the drivers, but never starts motion;
 *     a fresh host M command is still required.
 *
 * SERIAL PROTOCOL  (115200 baud, '\n'-terminated ASCII lines)
 *   Host -> Mega:
 *     ARM                 arm the drivers (if E-stop ok)
 *     DISARM              disarm + stop
 *     M <left> <right>    per-side duty, floats in [-1.0, 1.0]  (also a heartbeat)
 *     STOP                target duty 0 (stays armed)           (also a heartbeat)
 *     PING                heartbeat only; Mega replies "PONG"
 *   Mega -> Host (telemetry, every TELEM_MS):
 *     T <state> <Lduty> <Rduty> <encLF> <encLR> <encRF> <encRR> <estop>
 *       state: 0=DISARMED 1=ARMED 2=ESTOP
 *       estop: 1=tripped 0=ok
 *   Mega -> Host (acks): "OK ARM", "OK DISARM", "ERR <reason>", "PONG"
 *
 * PIN MAP — see docs/motion-perfboard-wiring-el.md §4.
 */

#include <Arduino.h>

// ---- BTS7960 control pins -------------------------------------------------
const uint8_t LEFT_RPWM  = 5;   // D5  PWM  (left forward)
const uint8_t LEFT_LPWM  = 6;   // D6  PWM  (left reverse)
const uint8_t LEFT_EN    = 30;  // D30      (left R_EN + L_EN tied)
const uint8_t RIGHT_RPWM = 9;   // D9  PWM  (right forward)
const uint8_t RIGHT_LPWM = 10;  // D10 PWM  (right reverse)
const uint8_t RIGHT_EN   = 31;  // D31      (right R_EN + L_EN tied)

// ---- Encoder pins (A on external-interrupt pins) --------------------------
const uint8_t ENC_LF_A = 2,  ENC_LF_B = 22;
const uint8_t ENC_LR_A = 3,  ENC_LR_B = 23;
const uint8_t ENC_RF_A = 18, ENC_RF_B = 24;
const uint8_t ENC_RR_A = 19, ENC_RR_B = 25;

// ---- Safety / user inputs (active-low, INPUT_PULLUP) ----------------------
const uint8_t START_ARM_PIN    = 32;  // optional arm button
const uint8_t ESTOP_STATUS_PIN = 33;  // optional E-stop aux contact
const uint8_t ARMED_LED_PIN    = 34;  // optional LED, through a series resistor

// ---- Tuning ---------------------------------------------------------------
const unsigned long BAUD          = 115200;
const unsigned long CMD_TIMEOUT_MS = 300;   // no heartbeat -> stop
const unsigned long CONTROL_MS     = 10;    // control loop period
const unsigned long TELEM_MS       = 100;   // telemetry period
const unsigned long BUTTON_DEBOUNCE_MS = 40;
const float  RAMP_PER_TICK = 0.02f;         // duty step per CONTROL_MS (~0.5s 0->full)
const float  DEADBAND      = 0.02f;         // below this, treat as zero

// ---- State ----------------------------------------------------------------
enum State { DISARMED = 0, ARMED = 1, ESTOPPED = 2 };
State state = DISARMED;

float targetLeft = 0.0f, targetRight = 0.0f;   // requested [-1,1]
float curLeft = 0.0f, curRight = 0.0f;         // ramped actual [-1,1]
unsigned long lastCmdMs = 0, lastControlMs = 0, lastTelemMs = 0;
bool startButtonRaw = HIGH, startButtonStable = HIGH;
unsigned long startButtonChangedMs = 0;

volatile long encLF = 0, encLR = 0, encRF = 0, encRR = 0;

char rxBuf[48];
uint8_t rxLen = 0;

// ---- Encoder ISRs (count on A edge, direction from B) ---------------------
void isrLF() { encLF += (digitalRead(ENC_LF_B) ? 1 : -1); }
void isrLR() { encLR += (digitalRead(ENC_LR_B) ? 1 : -1); }
void isrRF() { encRF += (digitalRead(ENC_RF_B) ? 1 : -1); }
void isrRR() { encRR += (digitalRead(ENC_RR_B) ? 1 : -1); }

// ---- Helpers --------------------------------------------------------------
bool estopTripped() { return digitalRead(ESTOP_STATUS_PIN) == LOW; }

void setDriverEnable(bool en) {
  digitalWrite(LEFT_EN,  en ? HIGH : LOW);
  digitalWrite(RIGHT_EN, en ? HIGH : LOW);
}

void updateArmedLed() {
  digitalWrite(ARMED_LED_PIN, state == ARMED ? HIGH : LOW);
}

void applySide(uint8_t rpwm, uint8_t lpwm, float duty) {
  if (duty > DEADBAND) {
    analogWrite(rpwm, (uint8_t)(duty * 255.0f));
    analogWrite(lpwm, 0);
  } else if (duty < -DEADBAND) {
    analogWrite(rpwm, 0);
    analogWrite(lpwm, (uint8_t)(-duty * 255.0f));
  } else {
    analogWrite(rpwm, 0);
    analogWrite(lpwm, 0);
  }
}

void stopOutputs() {
  curLeft = curRight = 0.0f;
  targetLeft = targetRight = 0.0f;
  applySide(LEFT_RPWM, LEFT_LPWM, 0.0f);
  applySide(RIGHT_RPWM, RIGHT_LPWM, 0.0f);
}

void doDisarm(const char* reason) {
  stopOutputs();
  setDriverEnable(false);
  state = (estopTripped() ? ESTOPPED : DISARMED);
  updateArmedLed();
  Serial.print(F("OK DISARM "));
  Serial.println(reason);
}

void doArm() {
  if (estopTripped()) { state = ESTOPPED; Serial.println(F("ERR estop")); return; }
  stopOutputs();
  setDriverEnable(true);
  state = ARMED;
  updateArmedLed();
  lastCmdMs = millis();   // grace period for first heartbeat
  Serial.println(F("OK ARM"));
}

void pollStartButton(unsigned long now) {
  bool raw = digitalRead(START_ARM_PIN);
  if (raw != startButtonRaw) {
    startButtonRaw = raw;
    startButtonChangedMs = now;
  }
  if (raw != startButtonStable && now - startButtonChangedMs >= BUTTON_DEBOUNCE_MS) {
    startButtonStable = raw;
    if (startButtonStable == LOW && state == DISARMED) {
      doArm();
    }
  }
}

float clampUnit(float v) { return v < -1.0f ? -1.0f : (v > 1.0f ? 1.0f : v); }

float rampToward(float cur, float tgt) {
  if (cur < tgt) { cur += RAMP_PER_TICK; if (cur > tgt) cur = tgt; }
  else if (cur > tgt) { cur -= RAMP_PER_TICK; if (cur < tgt) cur = tgt; }
  return cur;
}

// ---- Serial command parser ------------------------------------------------
void handleLine(char* line) {
  // tokenize
  if (strncmp(line, "M ", 2) == 0) {
    float l = 0, r = 0;
    if (sscanf(line + 2, "%f %f", &l, &r) == 2) {
      targetLeft  = clampUnit(l);
      targetRight = clampUnit(r);
      lastCmdMs = millis();
    } else {
      Serial.println(F("ERR parse"));
    }
  } else if (strcmp(line, "STOP") == 0) {
    targetLeft = targetRight = 0.0f;
    lastCmdMs = millis();
  } else if (strcmp(line, "ARM") == 0) {
    doArm();
  } else if (strcmp(line, "DISARM") == 0) {
    doDisarm("host");
  } else if (strcmp(line, "PING") == 0) {
    lastCmdMs = millis();
    Serial.println(F("PONG"));
  } else if (line[0] != '\0') {
    Serial.println(F("ERR cmd"));
  }
}

void pollSerial() {
  while (Serial.available()) {
    char c = (char)Serial.read();
    if (c == '\n' || c == '\r') {
      if (rxLen > 0) { rxBuf[rxLen] = '\0'; handleLine(rxBuf); rxLen = 0; }
    } else if (rxLen < sizeof(rxBuf) - 1) {
      rxBuf[rxLen++] = c;
    } else {
      rxLen = 0;  // overflow -> drop line
    }
  }
}

void sendTelemetry() {
  noInterrupts();
  long lf = encLF, lr = encLR, rf = encRF, rr = encRR;
  interrupts();
  Serial.print(F("T "));
  Serial.print((int)state);          Serial.print(' ');
  Serial.print(curLeft, 3);          Serial.print(' ');
  Serial.print(curRight, 3);         Serial.print(' ');
  Serial.print(lf); Serial.print(' ');
  Serial.print(lr); Serial.print(' ');
  Serial.print(rf); Serial.print(' ');
  Serial.print(rr); Serial.print(' ');
  Serial.println(estopTripped() ? 1 : 0);
}

void setup() {
  Serial.begin(BAUD);

  pinMode(LEFT_RPWM, OUTPUT);  pinMode(LEFT_LPWM, OUTPUT);  pinMode(LEFT_EN, OUTPUT);
  pinMode(RIGHT_RPWM, OUTPUT); pinMode(RIGHT_LPWM, OUTPUT); pinMode(RIGHT_EN, OUTPUT);

  pinMode(ENC_LF_A, INPUT_PULLUP); pinMode(ENC_LF_B, INPUT_PULLUP);
  pinMode(ENC_LR_A, INPUT_PULLUP); pinMode(ENC_LR_B, INPUT_PULLUP);
  pinMode(ENC_RF_A, INPUT_PULLUP); pinMode(ENC_RF_B, INPUT_PULLUP);
  pinMode(ENC_RR_A, INPUT_PULLUP); pinMode(ENC_RR_B, INPUT_PULLUP);

  pinMode(START_ARM_PIN, INPUT_PULLUP);
  pinMode(ESTOP_STATUS_PIN, INPUT_PULLUP);
  pinMode(ARMED_LED_PIN, OUTPUT);

  attachInterrupt(digitalPinToInterrupt(ENC_LF_A), isrLF, RISING);
  attachInterrupt(digitalPinToInterrupt(ENC_LR_A), isrLR, RISING);
  attachInterrupt(digitalPinToInterrupt(ENC_RF_A), isrRF, RISING);
  attachInterrupt(digitalPinToInterrupt(ENC_RR_A), isrRR, RISING);

  // Boot DISARMED: drivers off, outputs zero.
  setDriverEnable(false);
  stopOutputs();
  state = DISARMED;
  updateArmedLed();
  Serial.println(F("READY motion_mega DISARMED"));
}

void loop() {
  pollSerial();

  unsigned long now = millis();
  pollStartButton(now);

  // E-stop has absolute priority.
  if (estopTripped() && state != ESTOPPED) {
    doDisarm("estop");
    state = ESTOPPED;
  }
  // Recover from ESTOPPED to DISARMED once contact clears (still needs ARM).
  if (state == ESTOPPED && !estopTripped()) {
    state = DISARMED;
    updateArmedLed();
  }

  // Control loop: timeout + ramp + output.
  if (now - lastControlMs >= CONTROL_MS) {
    lastControlMs = now;

    if (state == ARMED) {
      // Command timeout -> immediate zero output (stay armed).
      if (now - lastCmdMs > CMD_TIMEOUT_MS) {
        stopOutputs();
      }
      curLeft  = rampToward(curLeft,  targetLeft);
      curRight = rampToward(curRight, targetRight);
      applySide(LEFT_RPWM,  LEFT_LPWM,  curLeft);
      applySide(RIGHT_RPWM, RIGHT_LPWM, curRight);
    } else {
      // Not armed: ensure outputs are zero and drivers disabled.
      stopOutputs();
      setDriverEnable(false);
    }
  }

  if (now - lastTelemMs >= TELEM_MS) {
    lastTelemMs = now;
    sendTelemetry();
  }
}

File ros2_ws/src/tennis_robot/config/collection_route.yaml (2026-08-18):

# Explicit Gazebo MVP runtime source for CollectionRouteConfiguration.
# calibration_artifact is intentionally absent: the caller supplies its path.
schema_version: collection-route/v2
mechanical:
  capture_half_width_m: 0.17
  ball_radius_m: 0.033
  robot_length_m: 0.8
  robot_width_m: 0.6
  funnel_length_m: 0.4
  funnel_width_m: 0.34
  safety_margin_m: 0.05
  # Conservative planning radius.  The hard controller limit remains
  # 1.25 1/m (0.8 m mechanical radius); planning at 1.25 m limits nominal
  # curvature to 0.8 1/m and reserves about 56% for closed-loop correction.
  minimum_turning_radius_m: 1.25
  maximum_curvature_per_m: 1.25
  minimum_entry_m: 0.2
  # Keep approach geometry at the last full-route baseline. Increasing this
  # to 1.9 m reduced pristine frozen-snapshot coverage from 9/10 to 6/10 by
  # turning three otherwise selectable targets into route conflicts.
  minimum_run_in_m: 1.0
  minimum_run_out_m: 0.3
  minimum_mechanical_ball_spacing_m: 0.5
safety:
  static_obstacle_clearance_m: 0.1
  costmap_inflation_m: 0.15
  trajectory_tube_radius_m: 0.2
  progress_window_m: 0.5
  max_parallel_heading_error_rad: 0.2
  collector_start_timeout_s: 2.0
  # The final ball may still be between the entry and confirmation beams when
  # Nav2 reaches the terminal pose. Allow the bounded 1.5–5.0 s intake drain
  # to finish before treating collector shutdown as faulty.
  collector_stop_timeout_s: 6.0
  safety_pause_timeout_s: 10.0
scan:
  # 0.6 (was 1.0): demanding a valid spatial observation at ALL 18 scan headings
  # is fragile — on the distributed sim the RGB/depth sync slop + rotation timing
  # drop a few headings (e.g. 12/18 covered) even though the scan already
  # confirmed enough balls for a route. Require a majority of headings instead;
  # the confirmed tracks still drive planning.
  required_coverage_fraction: 0.6
  # 90 s (was 20): the 360° scan visits 18 headings, each waiting on a
  # perception frame. Distributed (perception + YOLO on the Pi ARM CPU consuming
  # the PC camera over DDS) runs ~3 s/step, so 20 s only covered 6/18 before the
  # wall-clock guard aborted. 90 s clears the full sweep; a fast local run still
  # finishes well under it.
  scan_timeout_s: 90.0
  minimum_confirmation_count: 2
feasibility:
  heading_sample_count: 16
  confidence_multiplier: 2.0
  tracking_lateral_error_bound_m: 0.04
  capture_safety_margin_m: 0.05
  footprint_clearance_radius_m: 0.50
  tangent_activation_distance_m: 0.75
  max_parallel_heading_error_rad: 0.20
  # Boundary recovery deliberately runs the centreline one configured funnel
  # mouth half-width away from a net/fence ball.  The outer cheek then contacts
  # the ball while the canonical 0.50 m swept-disk clearance still protects the
  # chassis and the rest of the route.  Front cheek tips are at y=+/-0.205 m in
  # the URDF; this is a contact experiment, not the nominal capture corridor.
  boundary_recovery_contact_offset_m: 0.205
connector:
  max_connector_length_m: 20.0
  # A second mission can begin with the chassis facing almost directly away
  # from every target.  The former 1.5 rad per-arc cap prohibited the required
  # forward U-turn even though the canonical 1.25 m radius, collision and
  # self-intersection checks all accepted it.  Keep each CSC arc below pi while
  # allowing the bounded two-arc manoeuvre.
  max_connector_arc_angle_rad: 3.0
  max_connector_total_turn_rad: 6.0
  # Connectors used to be generated only at the 1.25 m minimum turning radius, so
  # 76% of the route was motion that could never collect: an arc that tight has a
  # pure-pursuit heading lead near 0.24 rad, well past the capture gate.  Adding
  # gentler radii lets the search choose a sweeping curve that takes balls on the
  # way instead of a tight hop between dedicated straight passes.  1.0 must stay
  # so the original tight geometry remains available.
  sweep_radius_multipliers: [1.0, 3.0, 6.0]
  # lookahead/(2R) is the pure-pursuit heading lead; with a 0.6 m lookahead and the
  # 0.15 rad capture gate this needs R > 2.0 m.  2.5 m keeps margin.
  capture_minimum_turn_radius_m: 2.5
cluster_heuristics:
  # Clustering guides the router; it never decides what is reachable.  Balls
  # within this distance seed the precomputed multi-pass shortcuts (macros) the
  # search may take in one expansion, and bias which successor is expanded
  # first.  Every pass inside a macro stays individually available, so any
  # interleaving of clusters remains reachable.
  cluster_threshold_m: 2.5
  maximum_clusters: 6
  maximum_macro_passes: 4
  # 0 disables macros entirely without changing which routes exist.
  maximum_macro_chains: 24
global_route_search:
  # Expansions are the deterministic budget; maximum_planning_time_s is the
  # safety net behind it.  One expansion is one successor *evaluation*, so the
  # budget buys the same amount of work whatever the pacing below does with it --
  # which is why this reads 600k where the identical behaviour read 150k while
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

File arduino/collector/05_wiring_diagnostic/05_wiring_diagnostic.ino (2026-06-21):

/*
  Collector Wiring Diagnostic

  Purpose:
    Shows whether the first collector wiring is alive before running full logic.

  Pin map:
    D2  -> Encoder A
    D3  -> TB6612 PWMA
    D4  -> TB6612 AIN1
    D5  -> TB6612 AIN2
    D6  -> TB6612 STBY
    D7  -> Encoder B
    D9  -> IR #1 entry receiver signal
    D10 -> IR #2 exit receiver signal

  Power:
    Arduino 5V  -> TB6612 VCC, encoder VCC, IR VCC
    Arduino GND -> TB6612 GND -> 12V PSU -
    12V PSU +   -> TB6612 VM
    Motor red   -> TB6612 AO1
    Motor black -> TB6612 AO2

  Serial Monitor:
    Baud rate: 115200
    Line ending: No line ending

  Commands:
    i = print wiring status once
    p = short low-PWM forward pulse, then stop
    f = forward low PWM
    r = reverse low PWM
    s = stop/coast
    b = brake
    + = increase PWM by 10, max 120
    - = decrease PWM by 10
    ? = help

  Expected IR logic for Adafruit break beam receivers with INPUT_PULLUP:
    LOW  = beam broken / blocked
    HIGH = beam clear / unbroken
*/

const byte ENCODER_A_PIN = 2;
const byte MOTOR_PWM_PIN = 3;
const byte MOTOR_AIN1_PIN = 4;
const byte MOTOR_AIN2_PIN = 5;
const byte MOTOR_STBY_PIN = 6;
const byte ENCODER_B_PIN = 7;
const byte IR_ENTRY_PIN = 9;
const byte IR_EXIT_PIN = 10;

const byte START_PWM = 60;
const byte MAX_SAFE_PWM = 120;
const unsigned int PULSE_MS = 300;

volatile long encoderCount = 0;
byte motorPwm = START_PWM;
char motorMode = 's';

void onEncoderAChange() {
  bool a = digitalRead(ENCODER_A_PIN);
  bool b = digitalRead(ENCODER_B_PIN);

  if (a == b) {
    encoderCount++;
  } else {
    encoderCount--;
  }
}

bool beamBroken(byte pin) {
  return digitalRead(pin) == LOW;
}

const char *beamText(byte pin) {
  return beamBroken(pin) ? "BROKEN" : "CLEAR";
}

void motorCoast() {
  analogWrite(MOTOR_PWM_PIN, 0);
  digitalWrite(MOTOR_AIN1_PIN, LOW);
  digitalWrite(MOTOR_AIN2_PIN, LOW);
  motorMode = 's';
}

void motorBrake() {
  analogWrite(MOTOR_PWM_PIN, 0);
  digitalWrite(MOTOR_AIN1_PIN, HIGH);
  digitalWrite(MOTOR_AIN2_PIN, HIGH);
  motorMode = 'b';
}

void motorForward() {
  digitalWrite(MOTOR_STBY_PIN, HIGH);
  digitalWrite(MOTOR_AIN1_PIN, HIGH);
  digitalWrite(MOTOR_AIN2_PIN, LOW);
  analogWrite(MOTOR_PWM_PIN, motorPwm);
  motorMode = 'f';
}

void motorReverse() {
  digitalWrite(MOTOR_STBY_PIN, HIGH);
  digitalWrite(MOTOR_AIN1_PIN, LOW);
  digitalWrite(MOTOR_AIN2_PIN, HIGH);
  analogWrite(MOTOR_PWM_PIN, motorPwm);
  motorMode = 'r';
}

void applyCurrentMode() {
  if (motorMode == 'f') {
    motorForward();
  } else if (motorMode == 'r') {
    motorReverse();
  } else if (motorMode == 'b') {
    motorBrake();
  } else {
    motorCoast();
  }
}

void printHelp() {
  Serial.println();
  Serial.println("Collector wiring diagnostic commands:");
  Serial.println("  i = print wiring status once");
  Serial.println("  p = short low-PWM forward pulse, then stop");
  Serial.println("  f = forward low PWM");
  Serial.println("  r = reverse low PWM");
  Serial.println("  s = stop/coast");
  Serial.println("  b = brake");
  Serial.println("  + = PWM +10, max 120");
  Serial.println("  - = PWM -10");
  Serial.println("  ? = help");
  Serial.println();
}

void printStatus() {
  noInterrupts();
  long count = encoderCount;
  interrupts();

  Serial.println("----- wiring status -----");
  Serial.print("TB6612 control pins: PWMA=D");
  Serial.print(MOTOR_PWM_PIN);
  Serial.print(" AIN1=D");
  Serial.print(MOTOR_AIN1_PIN);
  Serial.print(" AIN2=D");
  Serial.print(MOTOR_AIN2_PIN);
  Serial.print(" STBY=D");
  Serial.println(MOTOR_STBY_PIN);

  Serial.print("motor_mode=");
  Serial.print(motorMode);
  Serial.print(" pwm=");
  Serial.println(motorPwm);

  Serial.print("encoder: A raw=");
  Serial.print(digitalRead(ENCODER_A_PIN));
  Serial.print(" B raw=");
  Serial.print(digitalRead(ENCODER_B_PIN));
  Serial.print(" count=");
  Serial.println(count);

  Serial.print("IR entry D9 raw=");
  Serial.print(digitalRead(IR_ENTRY_PIN));
  Serial.print(" state=");
  Serial.println(beamText(IR_ENTRY_PIN));

  Serial.print("IR exit  D10 raw=");
  Serial.print(digitalRead(IR_EXIT_PIN));
  Serial.print(" state=");
  Serial.println(beamText(IR_EXIT_PIN));

  Serial.println("Power check with multimeter:");
  Serial.println("  TB6612 VCC->GND should be about 5V");
  Serial.println("  TB6612 VM->GND should be about 12V");
  Serial.println("  Arduino GND, TB6612 GND, and 12V PSU - must be common");
  Serial.println("-------------------------");
}

void pulseMotor() {
  Serial.print("short forward pulse pwm=");
  Serial.print(motorPwm);
  Serial.print(" for ");
  Serial.print(PULSE_MS);
  Serial.println("ms");

  motorForward();
  delay(PULSE_MS);
  motorCoast();

  Serial.println("pulse done, motor stopped");
}

void handleSerial() {
  while (Serial.available() > 0) {
    char cmd = Serial.read();

    if (cmd == 'i') {
      printStatus();
    } else if (cmd == 'p') {
      pulseMotor();
    } else if (cmd == 'f') {
      motorForward();
      Serial.println("cmd: forward");
    } else if (cmd == 'r') {
      motorReverse();
      Serial.println("cmd: reverse");
    } else if (cmd == 's') {
      motorCoast();
      Serial.println("cmd: stop/coast");
    } else if (cmd == 'b') {
      motorBrake();
      Serial.println("cmd: brake");
    } else if (cmd == '+') {
      motorPwm = min(MAX_SAFE_PWM, motorPwm + 10);
      applyCurrentMode();
      Serial.print("cmd: pwm=");
      Serial.println(motorPwm);
    } else if (cmd == '-') {
      motorPwm = max(0, motorPwm - 10);
      applyCurrentMode();
      Serial.print("cmd: pwm=");
      Serial.println(motorPwm);
    } else if (cmd == '?') {
      printHelp();
    }
  }
}

void setup() {
  Serial.begin(115200);

  pinMode(ENCODER_A_PIN, INPUT_PULLUP);
  pinMode(ENCODER_B_PIN, INPUT_PULLUP);
  pinMode(IR_ENTRY_PIN, INPUT_PULLUP);
  pinMode(IR_EXIT_PIN, INPUT_PULLUP);

  pinMode(MOTOR_PWM_PIN, OUTPUT);
  pinMode(MOTOR_AIN1_PIN, OUTPUT);
  pinMode(MOTOR_AIN2_PIN, OUTPUT);
  pinMode(MOTOR_STBY_PIN, OUTPUT);

  attachInterrupt(digitalPinToInterrupt(ENCODER_A_PIN), onEncoderAChange, CHANGE);

  digitalWrite(MOTOR_STBY_PIN, HIGH);
  motorCoast();

  Serial.println("Collector wiring diagnostic ready");
  Serial.println("Open Serial Monitor at 115200 baud. Send '?' for commands.");
  Serial.println("Start with 'i'. Then block each IR beam, rotate the shaft by hand, and try 'p'.");
  printStatus();
}
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

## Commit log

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2026-06-04 Fix 6 ROS 2 correctness bugs found in code review
    - controller_node: add missing _pub_command publisher so mode transitions
    propagate to CommandBridgeNode and web panel
    - controller_node: remove vacuous lz=-0.12 z-check in _check_collection;
    /sim/balls provides no z coordinate so the check was always True
    - controller_node: move _publish_command inside _search_complete_reported
    guard to prevent 31 Hz file-write storm after search completes
    - lidar_survey: accept lidar_angle_min/angle_increment from LaserScan and
    use them in _scan_points_world/_scan_points_local instead of fixed 2π
    formula, fixing boundary mapping for non-360° sensors
    - lidar_survey: fix _detect_net_frame confiden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
    [controller_node.py]
2026-06-04 Add Gazebo Harmonic migration: world, robot SDF, bridge, Docker
    - gazebo/models/tennis_robot/model.sdf: full robot SDF with diff_drive,
    intake roller joint, 360° LiDAR, camera, depth, IR beam-break sensors.
    Geometry extracted from worlds/tennis_court.wbt (wheels r=0.11m, track
    0.48m, LiDAR at z=0.72m). Motor naming corrected to ROS convention.
    - gazebo/models/tennis_court/model.sdf: static court with red clay ground,
    court lines, net, posts, perimeter fence, and floodlight poles.
    - gazebo/worlds/tennis_court.sdf: world file with 18 tennis balls at
    positions matching the Webots world, plus all required Gazebo plugins.
    - gazebo/bridge_config.yaml: ros_gz parameter bridge mapping all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
    [model.sdf, tennis_court.sdf]
2026-06-04 Fix 3 Gazebo startup errors
    - model.sdf: correct wheel inertia tensor — Izz (spin axis) = 0.001513,
    Ixx=Iyy (transverse) = 0.000889. Previous values had ixx+izz < iyy
    which violates the triangle inequality and caused 'invalid inertia' error
    - tennis_court.sdf: replace <light type=\"ambient\"> (not valid in SDF 1.9)
    with <scene><ambient> which is the correct way to set ambient light in
    Gazebo Harmonic
    - Dockerfile.gazebo: remove --symlink-install from colcon build — symlink
    install creates .egg-info (not .dist-info) so importlib.metadata cannot
    find the package, causing PackageNotFoundError at node startup
    [model.sdf, tennis_court.sdf]
2026-06-04 Fix PackageNotFoundError and PosePublisher startup errors
    - Dockerfile.gazebo: add pip install after colcon build — colcon uses
    setup.py install which creates .egg-info, but importlib.metadata only
    finds .dist-info directories. pip install creates the correct .dist-info
    so that entry point scripts can locate the package at runtime.
    - tennis_court.sdf: remove PosePublisher world plugin (must be attached
    to a model, not the world). SceneBroadcaster already publishes all model
    poses to /world/tennis_court/pose/info — no extra plugin needed.
    - tennis_court.sdf: remove ODE max_vel/surface_layer from constraints
    (not valid SDF 1.9 elements, caused harmless but noisy warnings).
    Co-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
    [tennis_court.sdf]
2026-06-04 Fix pip prefix, court visuals and layout
    Dockerfile.gazebo: pip install with --prefix /ros2_ws/install/tennis_robot
    so .dist-info lands in the same site-packages that PYTHONPATH already
    includes, not in system Python; rclpy is now reachable.
    tennis_court model.sdf:
    - Add singles sidelines at y=±4.115 m (were missing)
    - Add centre marks at baselines
    - Move net posts to y=±5.65 m (0.165 m outside doubles sideline)
    - Widen net wall to match post span (11.3 m)
    - Net visual: separate white top band + dark semi-transparent mesh body
    - Fences moved to x=±14.5 m, y=±7.5 m (larger professional margins)
    - Fence visual: green semi-transparent chain-link material
    - Floodlight poles repositioned to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
    [model.sdf]
2026-06-04 Add DAE meshes for chain-link fence and net rope pattern
    gazebo/scripts/gen_court_meshes.py:
    Generates fence_long.dae (15×4m, 1896 tris), fence_wide.dae (29.08×4m,
    3304 tris), net_mesh.dae (11.3×0.914m, 96 tris). Fence uses Cohen-
    Sutherland clipping to produce ±45° wire ribbons at 4 cm rhombus diamond
    spacing (1mm wire radius). Net uses horizontal ropes every 10cm + vertical
    strings every 30cm (3mm wire, top band thicker at 7.5mm).
    gazebo/models/tennis_court/model.sdf:
    Fence links use fence_long/wide.dae for visual, keep box collision (stable
    for LiDAR raycasting). Net link uses net_mesh.dae + separate white top band
    box. East/West fences have yaw=-π/2 so mesh X (hori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
    [model.sdf]
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2026-06-04 Fix SDF diffuse > 1.0 and rclpy ModuleNotFoundError
    - tennis_court.sdf: clamp sun diffuse from 1.05 to 1.0 (SDF requires
    color components in [0, 1])
    - Dockerfile.gazebo: add 'pip uninstall tennis-robot' before the prefix
    install to remove any cached system-level installation that causes
    the module to load from /usr/local without rclpy in sys.path
    Requires rebuild: docker compose --profile gazebo build gazebo
    [tennis_court.sdf]
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2026-06-04 Integrate SketchUp court model as visual overlay with bench collisions
    gazebo/models/tennis_court/meshes/tennis_court_skp.dae:
    Converted from worlds/Tennis Court with Fence.skp (SketchUp 8, free model
    from sketchupbox.com). 699 geometries, 8 materials, 1.1 MB.
    model.sdf: new skp_visual link loads the full DAE as visual overlay on top
    of the existing collision geometry. Coordinate mapping:
    scale = 0.016507 m/unit (23.77m court / 1440 SKP units)
    yaw = π/2 (aligns SKP Y-axis / court length to Gazebo X)
    pose = (-7.725, 3.3, 0) centres the court at (0,0,0)
    bench_north, bench_mid_north, bench_mid_south: collision boxes at DAE-
    derived positions (y = +3.39, +0.77, −1.31 m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
    [model.sdf]
2026-06-05 Two-point court survey: LiDAR net + baseline fence, fix 180° turn
    Implements Ros2LidarCourtSurvey two-phase flow:
    Phase 1 (FIND_BOUNDARY): ObstacleSurvey approaches and stops at net
    Phase 2 (FIND_BASELINE): turns 180°, drives to baseline fence, records
    baseline-to-fence gap from LiDAR range at court-line crossing
    Fix: suppress vision in the baseline survey leg so the camera sweeping
    over fences during rotation cannot trigger a premature stop at ~164°
    (heading_tolerance * 2 window). Fence detection uses LiDAR range only.
    Panel displays measured Left/Right fence margins from baseline_to_fence_m
    and shows source: "two_point_survey" in the status bar.
    Also adds: gate leaf meshes, f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
    [model.sdf, tennis_court.sdf]
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2026-06-05 Fix 3 survey issues found in telemetry
    - sideline_short_stop_range_m: 0.70 → 1.20 m (was below safety_slow 0.75m
    so robot stalled at 0.75m and timed out; 1.20m fires before any slowdown)
    - _classify: sparse+wide-span → "fence" (chain-link fence was misclassified
    as "net" because sparse; now uses angular span to distinguish the two)
    controller_node.py:
    - Remove direct DuckDB write from controller_node; control panel already
    calls import_survey() in _read_court_boundary() → no more lock conflict
    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
    [controller_node.py]
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2026-06-10 add manual D-pad controls to UI and robot controller
    - Replace mode buttons with D-pad (↑↓←→), 180° turn, Map Court, Collect, Stop
    - Hold-to-move for directional buttons using Pointer Events API with setPointerCapture
    - 180° is a single-click: controller auto-stops after ~170° rotation using yaw tracking
    - Disable D-pad and 180° button during autonomous operations (map/collect/search)
    - Guard in _effective_control_mode ignores manual commands while autonomous mode is active
    - Add move_forward/backward/left/right/turn_180 to SUPPORTED_MODES
    [control_bus.py, controller_node.py]
2026-06-10 Adopt ros2_control + Nav2/SLAM stack for autonomous survey
    Robot control:
    - Migrate from Gazebo plugins to ros2_control (gz_ros2_control sim backend,
    swappable for real hardware); diff_drive_controller + joint_state_broadcaster
    + lift wheel velocity controller; drive_actuator_node + twist_mux arbiter.
    Sensors:
    - Canonical sensor topic contract (/scan, /camera/*) shared sim/real;
    real_sensors.launch.py for rplidar + OAK-D drivers.
    Autonomous survey:
    - slam_toolbox mapping + Nav2 (RPP controller, costmaps from /scan) +
    explore_lite frontier exploration; autonomous_survey.launch.py orchestrator.
    Fixes:
    - Front caster geometry: coplanar contact at design pitch + self-aligning trail.
    -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
    [base.urdf.xacro, controllers.yaml, cyber_shell_panels.scad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]
2026-06-10 Set gz_frame_id on lidar/camera/IR sensors so TF frames match URDF (fixes slam_toolbox scan drop)
    [ir_beam.urdf.xacro, lidar.urdf.xacro, oak_d.urdf.xacro]
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2026-06-19 Survey v2: reliable completion, clean obstacles, complete map
    Negative run-off (fence latched on net before far fence mapped) now recoverable, not fail-loud; smart fence-artifact filter -> 0 false obstacles on empty court; decouple measurement from map completion (lock model early, keep driving full path); coverage return pass for loop-closure overlap; continuous net strand at LiDAR scan height; tests updated (8 waypoints, return pass, artifact filter).
    [model.sdf]
2026-06-23 4WD skid-steer redesign: level chassis, IMU+EKF fusion, survey net-crossing
    - Drivetrain: 2WD+casters -> 4WD skid-steer (4x 180mm driven wheels, 2/side,
    symmetric, no casters); level (un-pitched) chassis; base_footprint on ground
    - ros2_control + diff_drive_controller: 4 wheel joints (2 per side);
    wheel_separation 0.70 -> 1.0 (skid-steer odom correction); EKF owns odom TF
    - Sensors: lowered LiDAR so the scan plane (world ~0.713m) hits the net again
    (was scanning over it -> drove through); camera tilt preserved; added MPU6050
    IMU + robot_localization EKF fusing wheel vx + IMU yaw-rate
    - Survey: net-aware crossing (stop_short flag) so the net is not mistaken for the
    target fence; fas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
    [base.urdf.xacro, base_mounting_plate.scad, controllers.yaml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]
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2026-07-08 Fix intake capture physics: paddle roller, synced channel geometry, sim instrumentation
    Instrumented rosbag testing (8 collect_one runs) traced the capture failure
    through four root causes, all fixed:
    - Channel/scoop geometry was desynced from the roller tuning offsets
    (hardcoded 0.615/0.112): both generate_curved_scoop_mesh.py and the SDF
    collision patch now follow INTAKE_ROLLER_*_OFFSET_M.
    - A rigid fixed-axis cylinder cannot friction-capture a rigid ball
    (interference jams, clearance never grips), and a 1-DOF vertical spring
    carriage only yields vertically while the ball's orbit needs radial
    compliance (every run stalled at fwd=-75mm). Replaced with the original
    paddle-wheel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
    [curved_scoop.stl, drivetrain.urdf.xacro, intake_debug_camera.urdf.xacro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]
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2026-07-08 Add spiral guide exit, align court visual/collision, log tests 10-12
    - Spiral guide (R 109->101 over 50deg wrap): a concentric guide can never
    end inside the paddles' 83mm drive circle, so the ball always parked just
    out of reach (tests 9-10). With the taper the exit edge sits deep in the
    drive zone; 14mm taper was too aggressive (ball slipped between fully
    bent paddles, test11), 8mm transports cleanly (test12).
    - Court ground collision aligned to its visual (-0.01 pose): the physics
    surface sat 10mm above the visible court, making balls/robot appear to
    float and offsetting all ground-truth z by +10mm.
    - Deflector raised to a safety-net position out of the exit trajectory.
    - Rema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
    [curved_scoop.stl, funnel.urdf.xacro, model.sdf]
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2026-07-11 Dual-wheel intake: Phase 0-3 implementation, bench, and Phase 3 handoff PASS
    Replace the single top roller with the dual-wheel side-pinch concept
    (docs/dual-wheel-intake-design-el.md) and validate it through the
    deterministic bench, phases 1-3 of the Concept Validation Plan:
    - Geometry/actuation: two vertical-axis intake wheels on sprung prismatic
    y-carriages (SDF-patched springs), per-wheel contact sensors, two-motor
    counter-rotation via intake_wheel_velocity_controller, GB37Y3530-251R
    limits (26.3 rad/s / 1.77 Nm), env-tunable tilt/gap/radius/nip and
    hypothetical-motor overrides, Phase gates via enable_funnel/enable_ramp.
    - Bench: sweep axes for wheel geometry/speeds/tilts/lateral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
    [basket.urdf.xacro, controllers.yaml, curved_scoop.stl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]
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2026-07-11 Live integration: winning defaults, low-hopper sensing, Jazzy motion chain
    Make the Phase 1-4 bench-proven intake geometry the default everywhere
    (generator, mesh script, xacro args, sweep harness, analyzer, run_ubuntu.sh
    fallbacks) and add full dual-wheel env passthrough to docker-compose (it
    previously forwarded only roller-era vars).
    Adapt collection sensing to the low hopper: basket IR beam pair drops from
    the scoop-era 0.158 to 0.085 ground (rolling-ball equator), and the
    controller's basket zone becomes x -0.12..0.42 with min ball z 0.075.
    Fix the live motion chain, dead twice over on native Jazzy (debug-log #43):
    the motor adapter published to bare /cmd_vel, which the gz bridge fed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
    [basket.urdf.xacro, curved_scoop.stl, tennis_robot.urdf.xacro]
2026-07-11 collect_one live approach: lock refresh, capture profile, wheel gate, odom fusion
    Four verified layers between "robot drives" and "ball reaches the wheels",
    each measured live against Gazebo ground truth (debug-log #44):
    - Perception validated: YOLO+depth world positions match ground truth to
    7.5 cm at 1.1 m; the pipeline was never the problem.
    - collect_one locked its target once at first sighting (3-5 m out, max
    error) and drove blind to that stale point. The lock now refreshes on
    every nearer sighting (0.6 m gate against target stealing), shrinking the
    frozen error to the last-visible ~7 cm.
    - Capture profile matched to the bench-proven intake: switch to the 0.14 m/s
    creep at 1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
    [tennis_robot.urdf.xacro]
2026-07-12 Basket v2: sunken removable mesh bin, rear battery bay, external lidar mast
    Replace the scoop-era basket with the bin designed in
    docs/basket-bin-redesign-spec-el.md (user decisions: ~50 balls, removable
    wire-mesh bin, sunken floor for retention):
    - Bin interior x 0.02-0.42, +-0.14, floor at 0.030 ground through a REAL
    chassis-plate opening (plate is now two side strips + a rear block): a
    ball is retained by 25 mm of depth below the 0.055 jump lip instead of
    the old 3 mm step, and the bin bottom keeps 25 mm of ground clearance.
    - Battery pack (user's 19.8x16.6x17 cm, 6.26 kg) modeled with real mass on
    the rear deck as a counterweight to the front intake overhang.
    - Lidar mast moves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
    [base.urdf.xacro, basket.urdf.xacro, battery.urdf.xacro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]
2026-07-12 Rolling-ball fix: lower jump lip to 0.045, honest hopper-entry criterion
    The deterministic drive-speed sweep reproduced the live #44 failure
    exactly: at 0.14-0.40 m/s the ball arrives rolling with the robot, takes a
    weaker kick (peak 0.075-0.083 vs the 0.088 the old lip required) and
    settles in the jump-base wedge. The key discovery is that the previous
    winning geometry passed on a knife edge - at 0.12 m/s the peak equalled
    the requirement exactly, so +0.02 m/s was enough to break it. Max wheel
    speed (26.3 rad/s) changed nothing: the kick is geometry-limited, so the
    headroom has to come from lowering the requirement.
    The v2 sunken bin makes that possible: lip 0.055 -> 0.045 and bin floor
    0.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
    [curved_scoop.stl, tennis_robot.urdf.xacro]
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2026-07-14 Full-basket 45-ball collection: entry hood + launch profile defaults
    The 45-ball loaded basket failed two ways: stored balls escaped during
    entry, and the incoming ball bounced off the pile back out of the bin.
    Fixes (debug log #54-56):
    - Entry hood (roof + side cheeks, rear overhang 40mm, rear clearance
    120mm): stored retention 45/45 in every run since.
    - Controlled-launch ramp profile clears the pile where wheel-only
    rolling entry is marginal: 5x repeatability gate at load 45 gave
    launch 5/5 PASS vs rolling 2/5 FAIL; unloaded regression 5/5.
    - Launch profile + hood are now the defaults across the whole fallback
    chain (generator, scoop mesh, xacro, sweep harness, docker-compose,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
    [basket.urdf.xacro, curved_scoop.stl, ros2_control.urdf.xacro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]
2026-07-14 OpenSCAD basket-bin-v2 model + spec sync with validated hood
    cad/basket-bin-v2/: parametric model of the sim-validated basket v2.1
    plus entry hood (debug log #45-#57). params.scad is the single source of
    dimensions (mm, ground frame), copied from the spec and basket xacro.
    Includes the removable mesh bin weldment (floor, walls, management tray,
    receiving chute, corner guards, centre lip, flange, handles), the
    chassis-mounted hood, a reference chassis context, and an assembly with
    exploded removal view. Renders and STL export verified in the openscad
    docker service.
    Two sim-to-build findings captured in the model and README:
    - The sim hood cheeks interpenetrate the bin corner guards (fixed l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
    [assembly.scad, bin.scad, chassis_context.scad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]
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2026-07-14 route_capture_probe: ground-truth instrumentation for unconfirmed captures
    First sim run (collection-route-debug-log-el #2): 4/11 balls collected and
    confirmed through Nav2 legs + fine approach, but the 5th physically caught
    ball never confirmed and the mission kept chasing the dead-reckoned lock.
    Every ~2 s of fine approach the controller now logs the nearest sim ball in
    robot-local coordinates (same transform as the basket-volume check) plus
    beam/latch/behavior state, so the next stall shows on its own whether the
    ball sits in the basket, the throat, or was plowed aside.
    [controller_node.py]
2026-07-15 Credit deck-parked balls as collected; probe lock-vs-truth error
    Run 2 evidence (collection-route-debug-log-el #3): centered approaches
    (|ly| <= 0.11) captured cleanly in seconds, but approaches arriving 2-3x
    outside the funnel's validated +/-80 mm lateral envelope launched the ball
    sideways onto the chassis deck (z 0.058, ly 0.2-0.47) — outside the strict
    bin-interior scoring volume, so the mission chased a dead-reckoned phantom
    for 20-30 s per ball and once confirmed off the WRONG ball.
    New collection_scoring.onboard_ball_zone(): bin gate unchanged, plus a
    deck zone covering the robot body; _check_sim_collection credits both and
    logs sim_collection_credit{zone} so deck landings stay mea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
    [collection_scoring.py, controller_node.py]
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2026-07-15 Net-collision fixes: timeout-first approach, phantom gate, LiDAR guard, real net line, narrower funnel exit
    Run 3 drove into the net chasing a phantom map entry for 78 s
    (collection-route-debug-log-el #6). Four roots, four fixes:
    - The approach gave_up/timeout check now runs BEFORE every early-return
    branch (the turn-toward-target branch used to starve it).
    - Phantom gate: no live sighting within the relock gate by MISSING_SCAN_S
    from the 1.3 m standoff marks the stop missing instead of dead-reckoning
    a capture into whatever stands there.
    - LiDAR forward guard during fine approach (COLLECT_ROUTE_FRONT_BLOCK_M,
    1.45 m from the mast = ~15 cm before funnel contact): the capture stream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
    [funnel.urdf.xacro]
2026-07-15 Intake log #59: narrowed funnel cheeks bench-VALIDATED to ±0.14 lateral
    1x envelope sweep (0.0-0.14) all 6/6 required; 5x repeatability gate 5/5
    at 0.12 and 5/5 at 0.14 (one startup flake rerun cleanly). The validated
    capture envelope doubles from ±0.08 to ±0.14, covering the worst approach
    error measured in the collect_route runs.
    [assembly.scad]
2026-07-15 Target-aware sightings + drift-following nav goals (run-4 misses)
    Run 4 was the first full route_complete (8/12 collected, no net contact,
    no stalls) but its 4 'missing' balls were real (seen_count 174-757):
    - With ball clusters the mission only ever saw the detection nearest the
    ROBOT, so the pursued ball 'had no live sighting' and the phantom gate
    mis-fired. The controller now feeds the detection nearest the mission's
    current target (1.5 m gate, freshness-checked), falling back to the
    nearest-to-robot observation.
    - Retries drove to the plan-time standoff even after the ball had been
    nudged away. The nav phase now follows the live map entry: >0.3 m drift
    refreshes the stop posi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
    [controller_node.py]
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2026-07-15 Pose-divergence watchdog + nav-rejection cascade abort
    Run 6: four clean collections (first zone=bin credit — the narrowed
    funnel launched straight into the basket), then a 17 s 'failed to make
    progress' leg and instant rejections of every subsequent goal; the
    reverse recoveries walked the robot ~3 m toward the fence while the user
    saw it nowhere near the net — belief vs reality likely disagree.
    - gazebo_extras now publishes /sim/robot_true_pose (raw world-frame
    ground truth); the controller records pose_error_m in every capture
    probe and the status, and emits a throttled pose_divergence event
    above 1 m. Existing lock_error_m cannot see pose drift because
    /sim/balls is re-projec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
    [controller_node.py]
2026-07-15 Calibrate map-world frame offset before measuring pose drift
    The Gazebo world frame is court-centred while the map frame anchors at
    the start pose (~8.4 m apart), so raw believed-vs-truth distance is a
    constant offset, not drift. The offset is captured at collect_route
    start and pose_error_m now reports deviation from it.
    [controller_node.py]
2026-07-15 Nav-phase probes; log #11: localization healthy, freeze is physical
    Run 7 verdict from the pose watchdog: believed-vs-truth stayed at the
    constant 8.0 m frame offset all run — no SLAM drift; the pose-jump
    hypothesis is dead. The stall pattern (controller_server feeding paths
    for 15 s while ground truth barely creeps, clear-costmap retries) points
    at a physical blockage; prime suspect is a ball wedged under the chassis
    since Nav2 legs plow straight through lidar-invisible balls. Capture
    probes now also run during nav legs (mission_phase field) to prove it.
    [controller_node.py]
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2026-07-20 Extend domain contracts for planner, executor and snapshot configuration
    Adds feasibility/connector/global-search/shared-pass/follow-up and Gazebo
    snapshot configuration groups, spatial observation types with typed
    rejection codes, planned crossings on funnel segments, and stricter plan
    status/geometry validation. Fixtures updated to the new configuration.
    [collection_route_types.py]
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2026-07-20 Deterministic offline route planner phases 3A-3D
    Per-ball straight-crossing feasibility with swept-disk clearance and
    tangent constraints (3A), forward CSC Dubins connector graph (3B1), exact
    bounded branch-and-bound global search with lexicographic scoring (3B2),
    bounded shared-pass generation (3C), and the plan_collection_route
    composition entry point returning an immutable CollectionRoutePlan (3D).
    Pure modules only; no runtime wiring.
    [collection_route_connector_graph.py, collection_route_global_solver.py, collection_route_planner_v2.py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]
2026-07-20 Fix runtime snapshot session and make scan coverage config single-source
    The Phase 2B session bridge broke when ScanSnapshotBuilder gained required
    scan-step/coverage/timeout arguments and finalize(now_s). The builder now
    takes only scan-instance data (scan_id, timestamp, pose, expected step IDs)
    and reads required_coverage_fraction and scan_timeout_s exclusively from
    configuration_snapshot.scan, so a snapshot can never disagree with its own
    serialized configuration. The session forwards expected_scan_step_ids and
    exposes finalize(now_s).
    [collection_snapshot_runtime_adapter.py]
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
